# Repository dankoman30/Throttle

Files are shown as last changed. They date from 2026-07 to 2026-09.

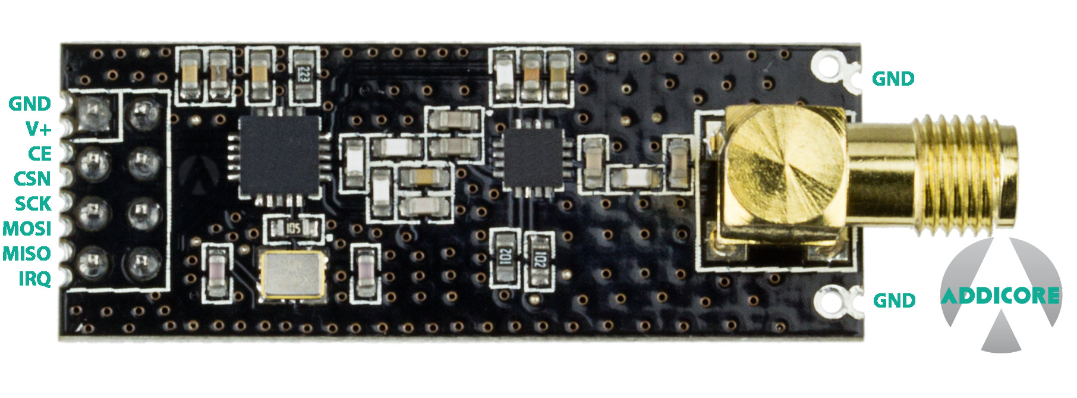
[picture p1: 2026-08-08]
DEVELOPMENT/assets/nRF24L01+/pinout.png

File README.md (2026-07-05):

# Throttle — drive-by-wire paramotor throttle

**A wireless, fail-safe paramotor throttle — squeeze the trigger, a radio link drives a servo that works the engine's throttle. No long mechanical cable running from your hand to the motor.**

The servo is **remote-mounted** (on the frame, not bolted to the engine) and pulls the throttle via a short push-pull cable — for space, vibration isolation, and a spring-return-to-idle fail-safe. See [`docs/PROJECT_DESIGN.md`](docs/PROJECT_DESIGN.md).

`Status: in development · pre-hardware · not flight-ready` — see [Status](#status--not-flight-ready).

Open firmware (and, in time, hardware) for a **drive-by-wire paramotor throttle**.
A handle-mounted STM32 reads a trigger, kill switch, start button, cruise button
and accessory switches, and transmits 5-byte packets at 80 Hz over an nRF24L01+
radio to a second STM32 near the engine. The receiver validates every packet,
runs a kill/start/run state machine, and drives a servo that pulls the physical
throttle cable — with an independent loss-of-signal watchdog that ramps the
engine back to idle if the link drops.

## Features

- **Fail-safe wireless kill** — latched on the handle so a brief press survives dropped packets; wired normally-closed so a broken wire = kill, with debounce against vibration glitches.
- **Loss-of-signal watchdog** — independent of the packet path; ramps the throttle to idle then holds it if the radio link drops, and won't hand control back until the link is stably restored.
- **Hold-to-crank electric start** — the starter runs while you hold the button and releases when the engine catches; bounded by a fast loss-of-signal abort and a hard max-crank cap so it can never run away.
- **Cruise control** — hold throttle hands-free; disengages on a second press, kill, or an upward trigger override. Resolved on the handle so the watchdog still overrides it.
- **Accessory outputs** — switch lights, smoke, etc., kept deliberately outside the safety-critical state machine.
- **Local battery monitors** — a 3–4 LED bar + low-battery buzzer on *each* unit, no return telemetry.
- **Layered safety by design** — packet validation (sync → CRC8 → sequence), kill-always-first command ordering, rate-limited servo motion, and a mechanical kill wired straight to the ignition, independent of any firmware.

> [!WARNING]
> ## Safety disclaimer — read this
>
> This is **DIY, safety-critical hardware**. It controls the throttle and
> ignition of a running two-stroke engine strapped to a person in flight.
>
> - It is **not certified** to any aviation or functional-safety standard, and
>   makes no claim of airworthiness.
> - You build, wire, configure, and fly it **entirely at your own risk**.
> - The firmware is provided **"AS IS", with no warranty** of any kind (see
>   `LICENSE`).
> - The design depends on a **mechanical kill switch wired directly into the
>   ignition line, independent of this firmware**. Do not remove it. The
>   authors accept no responsibility for injury or damage arising from use of
>   this project, from forks or modifications, or from removal or defeat of any
>   safety feature (mechanical kill, loss-of-signal watchdog, fail-safe wiring).
>
> If you intend to build and fly this, having someone familiar with the legal
> and liability implications of open safety-critical hardware review your plans
> is strongly advised.

## Status — not flight-ready

This project is **incomplete** and under active development. Known gaps that are
safety-relevant:

- **Engine-caught detection (`STARTING` → `RUNNING`) is not implemented.** The
  signal that tells the receiver the engine actually started (RPM sense,
  vibration, or a timed window) has not been chosen or built. **Do not fly**
  assuming the start sequence is finished.
- The firmware `.c` files are **HAL/RF24 stubs** — peripheral inits, the radio
  port, ADC/GPIO/PWM, and battery voltage divider values are placeholders that
  must be filled in during board bring-up.
- Timing/threshold constants are bench-tuning starting points, not validated.

See `docs/OPEN-ITEMS.md` for the full living list of unresolved questions and
action items, and `docs/PROJECT_DESIGN.md` for the rationale behind the design.

## Layout

```
src/common/     shared contract: packet protocol, CRC8, battery monitor (must stay identical both ends)
src/handle/     transmitter firmware (trigger, kill, start, cruise, accessories, battery)
src/receiver/   receiver firmware (validation, state machine, servo, watchdog, battery)
test/           host-side pure-logic tests (no hardware needed)
hardware/       schematics, PCB, mechanical, BOM (to come)
docs/           design doc, open items, architecture decision records
```

## Build & test

There is **no committed embedded build system yet** — building the firmware for
real requires generating an STM32CubeIDE project, wiring the peripheral inits,
and linking a HAL port of RF24 (TMRh20).

The pure logic (CRC8, sequence rollover, battery mapping, cruise, kill debounce)
can be tested on your PC with any C compiler:

```sh
# host-side logic tests
gcc -Wall -Wextra -Isrc/common -Itest test/test_logic.c -o test_logic && ./test_logic

# compile-check the firmware (stubs; no main/hardware)
gcc -c -Wall -Wextra -Isrc/common src/handle/handle_firmware.c    -o handle.o
gcc -c -Wall -Wextra -Isrc/common src/receiver/receiver_firmware.c -o receiver.o
```

## License

- **Firmware / software:** GNU General Public License v3.0-or-later — see
  `LICENSE`. Derivatives that are distributed must remain open under the same
  terms.
- **Hardware** (schematics, PCB, mechanical designs, once added): will be
  licensed under **CERN-OHL-S** (strongly reciprocal). See `hardware/README.md`.

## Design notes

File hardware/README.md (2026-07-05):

# Hardware

Schematics, PCB layouts, mechanical designs, and BOM for the throttle system.

Nothing here yet — this tree is scaffolding for upcoming design work:

```
schematics/   handle + receiver schematics (kill line, relays, RF, battery/LED bar, buzzer)
pcb/          board layouts
mechanical/   servo bracket, enclosures, mounting, connector plan
bom/          bill of materials
```

## License

Hardware design files in this directory (once added) are intended to be licensed
under **CERN-OHL-S v2** (CERN Open Hardware Licence, Strongly Reciprocal), which
is written for physical/board designs — separate from the **GPL-3.0-or-later**
that covers the firmware under `src/`. The `hardware/LICENSE` file will be added
alongside the first real design files.

## Safety note

See the top-level `README.md` safety disclaimer. In particular, the **mechanical
kill switch must be wired directly into the ignition kill line, independent of
any microcontroller or radio**, and must function with zero power to the
electronics. It is not — and must not be — controlled by firmware.

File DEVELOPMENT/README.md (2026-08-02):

# DEVELOPMENT

Bench-test rigs for bring-up and validation on real hardware, separate from
`src/` (the production firmware), `hardware/` (final board designs), and
`docs/` (project-level docs/ADRs).

Each subfolder here targets one physical unit and is meant to be built and
flashed with STM32CubeIDE against a dev board on a breadboard — proving out
logic before the corresponding real hardware (radio link, relays, production
servo, etc.) is wired up.

```
receiver/      bench rig for the receiver/servo-driver unit (current focus)
transmitter/   bench rig for the handle/trigger unit (deferred until receiver proves out)
```

**Safety note:** nothing under `DEVELOPMENT/` drives a real engine. The
receiver bench rig's kill/starter outputs are LED indicators only — no
relay, no ignition line, no starter solenoid. The mechanical kill switch
requirement in the top-level `README.md` and `hardware/README.md` still
applies to any real installation; it is not superseded by anything here.

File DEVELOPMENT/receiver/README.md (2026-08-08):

# DEVELOPMENT/receiver — bench rig (no radio yet)

**This doc covers the bench rig (`firmware/`) specifically.** For the
production receiver (real radio/servo/relays, not breadboard simulation),
see `receiver-prod/README.md`.

Runs the **real** receiver safety state machine
(`src/receiver/receiver_firmware.c`, completely unmodified) on an
STM32L432KC (Nucleo-32), fed by breadboard buttons and a potentiometer
instead of the nRF24L01+ radio link. This proves out kill/start/throttle/
watchdog behavior on real hardware before the radio, relays, and production
servo are wired up.

## What this does and doesn't test

**Does:**
- The receiver's packet validation (sync/CRC8/sequence), the kill latch and
  its stickiness, gated start (manual crank model), rate-limited throttle,
  and the independent loss-of-signal watchdog — all running the actual
  functions from `src/receiver/receiver_firmware.c` via
  `#include "receiver_firmware.c"` in `firmware/Src/bench_app.c` (see
  `docs/bench-behavior.md` for why this reuse approach was chosen and
  exactly what runs).
- A hand-built cruise mirror (small, bench-only reimplementation of the
  handle's `apply_cruise()`), since cruise is normally resolved on the
  handle and the receiver treats it as transparent.

**Does not test:**
- The radio link itself (packet loss patterns, RF interference, range).
- The starter solenoid / ignition-cut relays (LED stand-ins only here).
- Real engine-caught detection — the project has no tach (see
  `docs/OPEN-ITEMS.md`, ADR 0007); the green "engine running" LED here is a
  manual-release proxy, not a sensor reading.

## Layout

```
docs/
  wiring.md           pin-by-pin connections and resistor values
  cubemx-config.md    step-by-step CubeMX peripheral/pin/clock setup
  bench-behavior.md   full behavior spec + verification checklist
schematics/
  receiver-bench.md   breadboard schematic (markdown/ASCII)
firmware/
  Src/bench_app.c        ingestion (buttons/pot) + actuation (servo/display/buzzer/LEDs)
  Inc/bench_app.h
```

`firmware/` is a full STM32CubeMX-generated project (HAL/CMSIS drivers under
`Drivers/`, `firmware.ioc`, `.project`/`.cproject`) targeting the
NUCLEO-L432KC, with `bench_app.c`/`bench_app.h` wired into `main.c`. See
`docs/cubemx-config.md` for how it was configured and how to regenerate it.

## Board mod required

This board revision ships with solder bridges `SB16`/`SB18` closed by
default, which internally tie `PA6`↔`PB6` and `PA5`↔`PB7` together —
directly conflicting with this pin plan (kill button + yellow LED, servo
PWM + heartbeat LED). **Cut both before wiring anything** — see "Required
board mod" in `docs/wiring.md`.

## Bill of materials (this bench rig)

- STM32L432KC Nucleo-32
- 3× momentary pushbutton (start, cruise, kill)
- 1× B103 (10kΩ linear) potentiometer
- 1× piezo buzzer
- 1× 5611AH single-digit 7-segment LED display
- 1× SG90 micro servo
- 4× LED (green, red, yellow, + 1 for heartbeat — any color)
- Resistors: 7× for the 7-segment + 4× for the LEDs (~220–330Ω, see `docs/wiring.md`)

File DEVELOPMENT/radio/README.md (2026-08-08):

# DEVELOPMENT/radio — RF24 HAL port & radio link bring-up

**Status: all hardware has arrived (2026-08-06). Nothing built yet — starting
bring-up now.** This doc exists so picking this up doesn't require
re-deriving context from scratch.

## What this covers

Bringing up the actual nRF24L01+ link between `handle` and `receiver`. Both
`src/handle/handle_firmware.c` and `src/receiver/receiver_firmware.c` currently
have the entire radio path commented out (`radio.begin()`, `radio.write()`,
`radio.available()`/`radio.read()`, etc.) — the packet/state-machine logic on
both ends is already proven (`DEVELOPMENT/receiver/`), but nothing has actually
gone over the air yet. `docs/OPEN-ITEMS.md` flags the RF24 HAL port as staying
"on the critical path" for exactly this reason.

## Hardware inventory

**All arrived:**
1. **4x nRF24L01+PA+LNA modules**, from [Addicore](https://www.addicore.com/products/nrf24l01-pa-lna-with-antenna-2-4ghz-wireless-transceiver)
   (2 for the link + 2 spares). Clone chips (silkscreened as genuine Nordic
   but actually `SI24R1`/Beken parts) are a known problem for this exact
   module category and can't be reliably told apart by inspection (Nordic is
   fabless; markings vary by fab run) — buying multiple units from one
   reputable, consistent source is the practical mitigation, per ADR 0005's
   "not clone boards" requirement.
2. **2 additional STM32L432KC Nucleo-32 boards**, ordered directly from ST.
   Combined with the two already on hand, that's **4 total boards — only 1
   (the current receiver bench rig) has SB16/SB18 removed.** The other
   existing board and both new ones are stock/unmodified. See the SPI pin
   mapping note below before wiring any of the three unmodified boards for
   radio — it's directly relevant.
3. **Decoupling capacitors**, from Amazon:
   - ALLECIN 24-value electrolytic capacitor assortment kit (0.1µF–1000µF,
     10V/16V/25V/50V). Use the **16V or 25V** parts for this (not the 10V
     ones) — margin above the 3.3V rail, per the reasoning below.
   - 24-value / 480pc multilayer ceramic capacitor assortment kit
     (10pF–10µF) — covers the needed 0.1µF (100nF) many times over.
   - At each module's V+/GND pins, as close to the module as physically
     possible: one bulk **10–100µF** (from the electrolytic kit, 16V/25V) +
     one **0.1µF ceramic** (from the ceramic kit). **Known failure mode
     without this**: the PA+LNA variant draws real current spikes on TX
     (order ~100+mA) that a Nucleo's small onboard 3.3V LDO isn't sized for —
     one of the most common causes of "the radio just doesn't work / works
     intermittently" reports for this module. If it's still flaky with local
     decoupling, move to a dedicated 3.3V supply rather than the Nucleo's
     onboard rail.
4. **LONELY BINARY 8-Channel 24MHz USB Logic Analyzer Kit** (Amazon, ~$20;
   includes base module, breadboard breakout board, USB-A + Type-C cables,
   test clips, alligator clips). This is the same class of Cypress
   FX2LP-based hardware behind most "Saleae Logic clone" listings — pair it
   with **sigrok / PulseView** (free, open source) via its `fx2lafw` driver —
   worth doing a first smoke test now (confirm PulseView detects it) rather
   than waiting until it's needed mid-bring-up. PulseView has a **built-in
   SPI protocol decoder**, so feeding it
   SCK/MOSI/MISO/CSN shows decoded byte-level SPI transactions directly, not
   just raw waveforms — exactly what's needed to check nRF24 register
   reads/writes against the datasheet. Already on the toolchain wishlist in
   `docs/PROJECT_DESIGN.md`; would have shortened the SB16/SB18 debugging
   saga considerably had we had register-level SPI visibility instead of
   just GPIO reads. **Caution**: these clones typically have minimal input
   protection and are 3.3V-logic-only — fine for this SPI work (everything
   here is 3.3V) but don't probe 5V signals (e.g. the servo's 5V rail) with
   it.

No level shifting needed for the radio modules either way — their SPI inputs
are 5V-tolerant and the onboard regulator accepts 1.9–3.6V, a direct match
for the L432KC's 3.3V logic.

## SPI pin mapping: use PB3/PB4/PB5, not the PA5/PA6/PA7 default

**Important given 3 of the 4 boards don't have SB16/SB18 removed.** The
STM32L432KC's *default* SPI1 alternate-function mapping is `PA5`=SCK,
`PA6`=MISO, `PA7`=MOSI (AF5) — which is exactly the pin pair SB16/SB18
bridge to `PB6`/`PB7`. Using the default mapping on any unmodified board
would reproduce the same "two header pins are secretly one net" problem that
caused the kill-button saga, except manifesting as corrupted/garbled SPI
transactions rather than a flat stuck signal — likely *harder* to diagnose.

STM32L432KC also supports an **alternate SPI1 mapping on `PB3`/`PB4`/`PB5`**
(also AF5). **Use that mapping in CubeMX for the initial bring-up boards** —
it sidesteps the solder-bridge pins entirely, so none of the 3 unmodified
boards need SB16/SB18 removed just to get SPI working. One cosmetic note:
`PB3` is wired to the onboard LED `LD3`, so it'll flicker with SPI clock
activity — harmless, not a real conflict.

**Correction: this does not solve the receiver bench rig's pin problem** —
an earlier draft of this note incorrectly claimed it did. `PB4`/`PB5` are
already committed there too — Green LED and Red LED respectively
(`../receiver/docs/wiring.md`) — so the alternate mapping just trades one
conflict (solder bridges) for a different one (existing LED wiring) on that
specific board. That board's issue is genuinely zero free pins, not a
solder-bridge issue, and is already tracked separately below (Nucleo-64
fallback). The SPI mapping choice here only matters for the 3 fresh,
otherwise-unwired boards used for initial bring-up.

## Open design decision: adapt an existing STM32 fork, or write a minimal custom driver

Two community STM32 ports of TMRh20's RF24 library exist:
[TheDIYGuy999/RF24_STM32](https://github.com/TheDIYGuy999/RF24_STM32) and
[MarkKharkov/RF24](https://github.com/MarkKharkov/RF24). At least one report
([nRF24/RF24#501](https://github.com/nRF24/RF24/issues/501)) got basic SPI
communication working but had unreliable inter-node communication — so
adapting one of these isn't a guaranteed shortcut, just a possible head start.

Alternative: a minimal driver written directly against the nRF24L01+
datasheet's register map. Our protocol only needs a small slice of what the
full library supports — fixed 5-byte writes (handle), poll-based
`available()`/`read()` (receiver, no interrupt-driven mode needed), no ack,
no dynamic payload, no multicast. That's plausibly *less* total code than
untangling someone else's partial port, and easier to safety-review since
it would only contain what's actually used.

**Decided, 2026-08-06: minimal custom driver.** Implemented as
`DEVELOPMENT/radio/spi-bringup/spi-bringup/{Inc,Src}/nrf24.c/.h` — a
register-level driver against the nRF24L01+ (Plus) datasheet covering only
what this project's link needs (single/multi-byte register read/write,
init with no-ack/no-retry/250kbps+PA_HIGH/fixed 5-byte payload). Chosen over
adapting TheDIYGuy999/RF24_STM32 or MarkKharkov/RF24 per the reasoning
above and ADR 0006 (pure STM32 HAL, no Arduino/STM32duino).

## Known integration constraint for later: pin budget

The receiver bench rig already committed **all 17 free GPIOs** on the
L432KC's Arduino-style header — "no margin" per `../receiver/docs/wiring.md`.
SPI (SCK/MOSI/MISO/CSN) + CE needs 4 more pins than that board has free
(IRQ isn't needed since we poll, matching the commented-out
`radio.available()` calls already in both firmwares). This doesn't block
the initial bring-up here (happening on a fresh, otherwise-unused board),
but merging radio into the actual populated receiver rig later will need
either freeing pins (e.g. dropping the 7-segment readout or heartbeat LED)
or bumping to a Nucleo-64 — already noted as the fallback in
`docs/OPEN-ITEMS.md`.

## Suggested bring-up order (once hardware arrives)

1. **Single board + single module**: confirm SPI transactions work at all —
   read back a known register (e.g. `CONFIG`, datasheet default `0x08`) and
   confirm it matches. Logic analyzer on SCK/MOSI/MISO/CSN/CE to sanity-check
   the transaction shape against the datasheet timing diagrams.

   **Done, 2026-08-06.** `DEVELOPMENT/radio/spi-bringup/` (stock/unmodified
   Nucleo, SPI1 on PB3/PB4/PB5) read back `CONFIG` (addr `0x00`) as `0x08`
   and `STATUS` as `0x0E` — both exactly the nRF24L01+ datasheet's
   power-on-reset defaults for a fresh module. Confirmed via CubeIDE
   debugger (breakpoint after the transaction, `rx_buf[0]`/`rx_buf[1]`
   inspected as Expressions), not yet cross-checked against the logic
   analyzer's captured waveform — worth doing at some point for the
   SPI-mode/timing sanity check, but not blocking since the chip is already
   responding with correct data.

   **Multi-byte register read/write also confirmed, 2026-08-06.** The
   `nrf24.c` driver's `nrf24_write_reg_n`/`nrf24_read_reg_n` (used for the
   5-byte `RX_ADDR_P0`/`TX_ADDR` address registers) round-tripped correctly
   on hardware: after `nrf24_init()`, `CONFIG` read back `0x0A`, `RF_SETUP`
   read back `0x24`, and `RX_ADDR_P0` read back `{0xE7,0xE7,0xE7,0xE7,0xE7}`
   — all matching the values the driver itself wrote, confirming both the
   single- and multi-byte read and write paths. (An early single-call-per-byte
   implementation of the `_n` functions read back all-zero instead; fixed by
   building one cmd+data buffer and sending it in one `HAL_SPI_TransmitReceive`
   call, matching the single-register functions' already-proven pattern.)

2. ~~Decide fork-vs-custom-driver~~ — done, see above.
3. **Two boards + two modules**: a raw TX/RX smoke test independent of
   `handle_firmware.c`/`receiver_firmware.c` — e.g. one side sends an
   incrementing counter, the other prints/blinks it. Proves the link itself
   before touching either firmware.

   **Done, 2026-08-06.** Board A (PTX role) sends an incrementing counter
   every ~300ms; board B (PRX role) receives it and stores the value for
   debugger inspection (`rx_last_counter`), confirmed climbing by 1 each
   time, matching board A. Two real bugs found and fixed along the way —
   see `docs/decisions/0005-radio-choice-and-ignition-emi.md`'s 2026-08-06
   addendum for the full detail, since both are likely clone-chip symptoms
   relevant to eventual production hardware sourcing:
   - `nrf24_send_payload()` now clears `STATUS` and flushes the TX FIFO
     after every send (not just once at init) — without this, the TX
     board's FIFO latched permanently full (`MAX_RT` stuck set) within a
     few send cycles, despite `EN_AA`/`SETUP_RETR` both confirmed `0x00`.
   - `RF_SETUP` is temporarily `1Mbps` instead of the originally-intended
     `250kbps` — at 250kbps, zero packets were ever received even with the
     above fix and both boards side by side with antennas seated; switching
     to 1Mbps with no other change made reception immediately reliable.
     **This is a bring-up diagnostic swap, not a data-rate decision** — see
     the ADR 0005 addendum before assuming it holds for other hardware.

4. **Only after that**: wire the real `radio.*` calls into
   `handle_firmware.c` and `receiver_firmware.c` (currently fully
   commented-out stubs) and re-verify both bench rigs end-to-end over real
   radio instead of GPIO-simulated input.

   **Driver promoted, 2026-08-07; firmware wiring still blocked.** The
   proven `nrf24.c`/`nrf24.h` driver now lives in `src/common/` (shared,
   real, compiled code - not the bring-up project's copy), parameterized
   via an `nrf24_handle_t` so handle and receiver each supply their own SPI
   peripheral and CE/CSN pins rather than relying on hardcoded globals. Both
   firmware files' stub comments were updated to reference the real
   `nrf24_*` API (replacing stale TMRh20/RF24-library-style pseudocode from
   before the fork-vs-custom-driver decision), but the calls themselves stay
   commented, not live, because two concrete prerequisites are still open:
   - **Receiver**: no free GPIOs for SPI+CE — the bench rig already
     committed all 17 (see "Known integration constraint" above). Needs
     either freeing pins or a Nucleo-64 before real pins can be assigned.
   - **Handle**: no real hardware project exists yet at all (unlike the
     receiver's `DEVELOPMENT/receiver/firmware/`) — only the bring-up boards
     have been wired/programmed so far.

   Host compile-checks (`test/test_logic.c` and both firmware
   `.c` files) still pass unchanged - `nrf24.h`/`nrf24.c` depend on the real
   STM32 HAL and are new, not part of either check.

## Related docs

- `docs/decisions/0005-radio-choice-and-ignition-emi.md` — why
  nRF24L01+PA+LNA specifically, and the EMI environment to design around
  once this is mounted near a running engine.
- `docs/decisions/0001-no-radio-ack.md` (see the 2026-08-02 addendum) — no
  radio-level ack on the control uplink; a telemetry downlink is deferred
  and out of scope here.
- `docs/OPEN-ITEMS.md` — "RF24 HAL port" (Firmware TODOs) and "RF range
  test" (Hardware TODOs) entries.
- `docs/PROJECT_DESIGN.md` — toolchain list (logic analyzer already listed
  there).

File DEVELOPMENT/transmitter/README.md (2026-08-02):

# DEVELOPMENT/transmitter

Placeholder. Bench-test rig for the handle/trigger unit — deferred until the
receiver bench rig (`../receiver/`) proves out the approach (reusing the real
`src/handle/handle_firmware.c` state logic via the same
`#include "handle_firmware.c"` technique, driven by local trigger
pot/kill-switch/start-button/cruise-button input instead of real HAL reads).

Nothing here yet.

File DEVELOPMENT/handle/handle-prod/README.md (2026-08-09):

# DEVELOPMENT/handle/handle-prod — production handle/transmitter

Runs the **real** handle kill-latch/cruise/start-hold logic
(`src/handle/handle_firmware.c`, unmodified except small, reviewed hardware
fill-ins guarded by `HANDLE_PROD_BOARD` — see `Src/handle_app.c`'s header
comment) on an STM32L432KC (Nucleo-32), driving **real hardware**: the
trigger position sensor, kill/start/cruise/AUX1/AUX2 inputs, the nRF24L01+
radio TX, a tri-color status LED, and two AUX indicator LEDs. Compare
`DEVELOPMENT/receiver/receiver-prod/`, the same `#include`-reuse pattern
applied to the receiver side.

## Layout

```
docs/
  wiring.md         pin-by-pin connections, resistor values, known wiring gaps
Inc/handle_app.h     status LED color/priority behavior
Src/handle_app.c      real GPIO/ADC ingestion + radio TX + LED actuation
handle-prod.ioc       STM32CubeMX project file
```

Full STM32CubeMX-generated project (HAL/CMSIS drivers under `Drivers/`,
`STM32CubeIDE/.project`/`.cproject`) targeting NUCLEO-L432KC, with
`handle_app.c`/`handle_app.h` wired into `main.c`. Same linked-resource
caveat as receiver-prod: this project's `.project` tracks source files as
an explicit list, not a live directory scan — a new file in `Src/`/`Inc/`
needs a manually-added `<link>` entry or the IDE won't see it.

## Board

Reuses "board A" from `DEVELOPMENT/radio/spi-bringup/` — its radio wiring
(`NRF_CE`=`PA1`, `NRF_CSN`=`PA3`, SPI1 on `PB3`/`PB4`/`PB5`) already
matched this project's pin plan exactly, so it carried over unchanged;
everything else (trigger, kill/start/cruise/AUX1/AUX2, status + indicator
LEDs) was wired fresh on top. Same SB16/SB18-avoidance reasoning as
receiver-prod - see `docs/wiring.md` for the full pin table and why it
works.

## Status

- **2026-08-09: AUX2 restored, AUX1/AUX2 given distinct behavior,
  confirmed on real hardware.** AUX2 (smoke) was reinstated once adding
  its switch plus two indicator LEDs still fit the pin budget (16 of 17).
  AUX1 (strobe) is now LATCHED in firmware - toggle on/off on successive
  presses, same shape as `apply_cruise()`'s toggle - while AUX2 stays
  purely momentary, matching how AUX1 used to work. Deliberately kept
  both fully out of the receiver's kill/start/throttle state machine
  (discussed and reconfirmed, not just left over from before AUX2 was
  removed) - see `docs/OPEN-ITEMS.md`. Both indicator LEDs and both
  receiver-side outputs confirmed tracking correctly over the radio link.
- **2026-08-08: full command path confirmed on real hardware** — radio
  uplink to a receiver board, trigger position driving the servo live over
  the air, the start button correctly showing the cranking indication,
  cruise engage/disengage, and AUX1, all working end-to-end. Two real bugs
  were caught and fixed live during bring-up, both worth remembering:
  - **Cruise and AUX1 wired to GND instead of 3V3.** Those two inputs use
    the opposite pull convention from kill/start (pull-down vs pull-up),
    so their "other leg" needs to go to 3V3 - wiring all four buttons to
    GND by habit meant cruise/AUX1 could never read HIGH, so neither
    button did anything until corrected. See `docs/wiring.md`'s pin table
    note.
  - **Trigger ADC pull-down initially wired in series instead of
    parallel** - spliced into the wiper wire itself rather than as a
    separate leg to GND, which wouldn't have provided the intended
    fail-safe protection (the pin would still float if that wire broke)
    and would have starved the ADC's short sampling time. Corrected before
    it caused a real symptom.
- **Known, deliberate gap: the kill switch is currently a normally-open
  bench stand-in**, bridged closed with a jumper wire to unblock testing
  everything else. This design requires a genuinely normally-closed
  switch/contact block - swapping it is tracked in `docs/OPEN-ITEMS.md`.
- **Not yet measured**: real trigger ADC min/max at full release/pull (see
  `docs/wiring.md` "Trigger"); handle battery power source (sensing was
  dropped entirely, but the board still needs a real pack for field use).

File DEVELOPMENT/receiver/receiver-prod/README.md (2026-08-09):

# DEVELOPMENT/receiver/receiver-prod — production receiver

Runs the **real** receiver safety state machine
(`src/receiver/receiver_firmware.c`, unmodified except three small, reviewed
hardware fill-ins guarded by `RECEIVER_PROD_BOARD` — see `Src/prod_app.c`'s
header comment) on an STM32L432KC (Nucleo-32), driving **real hardware**:
the nRF24L01+ radio link, a servo, a tri-color status LED, and a local
start button — not breadboard simulation. Compare
`DEVELOPMENT/receiver/firmware/` (the bench rig), which proves out the same
state machine fed by local buttons/a pot instead of the radio, and doesn't
drive real actuator hardware.

## Layout

```
docs/
  wiring.md        pin-by-pin connections, resistor values, known wiring gaps
Inc/prod_app.h      LED behavior spec (heartbeat/kill/cranking/battery-low)
Src/prod_app.c      radio ingestion + servo/LED/relay/accessory actuation
receiver-prod.ioc    STM32CubeMX project file
```

Full STM32CubeMX-generated project (HAL/CMSIS drivers under `Drivers/`,
`STM32CubeIDE/.project`/`.cproject`) targeting NUCLEO-L432KC, with
`prod_app.c`/`prod_app.h` wired into `main.c`. Note: this project's
`.project` tracks source files as an explicit linked-resource list (not a
live directory scan) — see the commit that added `prod_app.c` if a new file
in `Src/`/`Inc/` doesn't show up in the IDE after a refresh.

## Board

Reuses "board B" from `DEVELOPMENT/radio/spi-bringup/` — the pin plan
deliberately avoids the `PA5`↔`PB7`/`PA6`↔`PB6` solder-bridge pairs, so this
board's SB16/SB18 were **not** desoldered (unlike the bench rig's board,
which required that mod). See `docs/wiring.md` for the full pin table and
why this works.

## Status

- **2026-08-09: AUX2 restored and confirmed on real hardware.** AUX2/PA10
  was never actually un-assigned in CubeMX during its 2026-08-08 removal,
  so restoring it was a code-only change (`apply_aux_outputs()` +
  `prod_app.c`'s GPIO write). Confirmed tracking the handle's AUX2 level
  correctly over the radio link, alongside AUX1 (now latched on the
  handle side, though this receiver treats both identically as plain
  level flags either way).
- **2026-08-08: Stage 1 confirmed on real hardware** (standalone, no radio
  link needed) — heartbeat LED blinking, servo settling at idle, and the
  local start button working end-to-end: press → blue LED (cranking),
  release → green LED (engine-running proxy). This is the first real-
  hardware confirmation of the local start button feature added this
  session (see the safety-reviewer-verified fix in
  `src/receiver/receiver_firmware.c`'s git history for the trigger-source
  tracking that closes the loss-of-signal-abort gap).
- **2026-08-08: Stage 2 confirmed on real hardware — full radio→servo path.**
  `spi-bringup`'s TX role now sends a real, protocol-valid
  `throttle_packet_t` (correct sync byte, sequence number, CRC8) with the
  throttle field slowly triangle-sweeping between idle and a moderate
  value. Board B's servo visibly tracked the sweep, live over the air —
  direct confirmation that `on_packet_received()`'s sync→CRC8→sequence
  validation is passing on real hardware for the first time, and that
  received throttle correctly flows through the rate-limited
  `step_toward_target()` path to the servo PWM. This is the first
  confirmed real-hardware run of the complete radio→validate→throttle→
  servo chain.
- **2026-08-08: Stage 3 confirmed on real hardware — wireless KILL and
  START, both correctly gated.** `spi-bringup`'s TX role now also
  auto-tests `CMD_FLAG_START_REQ` (every ~6s, held ~0.9s at idle throttle,
  well under `MAX_CRANK_MS` - always ends via voluntary release) and
  supports a debugger-triggered one-shot `CMD_FLAG_KILL` (not automatic,
  since KILL is sticky on the receiver and firing it on a timer would lock
  board B mid-test). Confirmed: wireless START correctly cycles blue
  (cranking) → green (engine-running proxy, stays lit - visible as an
  amber/yellow tint against the still-blinking red heartbeat) → back to
  normal; wireless KILL correctly latches solid red and stays there
  through a real board-A debug-session interruption, requiring a genuine
  board B power-cycle to re-arm (confirmed the local start button remains
  independently functional after re-arm, and that the TX side's one-shot
  `tx_send_kill` flag correctly self-resets). This is full real-hardware
  confirmation of every command path this board handles - kill, start
  (both wireless and local), and throttle - all currently deferred parts
  (kill relay, starter relay, battery sense) are wiring gaps, not logic
  gaps.
- **Known, deliberate wiring gaps**: kill relay, starter relay, battery
  sense — see `docs/wiring.md` "Known gaps".

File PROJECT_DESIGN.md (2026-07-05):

# Paramotor Drive-by-Wire Throttle — Project Design Doc

## Overview
Drive-by-wire paramotor throttle. Handle-mounted STM32 reads trigger position + kill switch + start button, transmits over 2.4GHz (nRF24L01+) to a remote-mounted STM32 near the engine, which drives a servo that pulls the physical throttle cable.

## Architecture

**Handle unit**
- STM32 (Nucleo-32 STM32L432KC or STM32G031 for prototyping)
- Reads trigger position via ADC (12-bit), smoothed with a simple exponential moving average filter
- Reads wireless kill switch and start button (start requires hold, not a single tap)
- Transmits fixed-size packet at 80Hz over nRF24L01+PA+LNA

**Remote unit**
- STM32 (same board family as handle for prototyping)
- Receives packets, validates, runs state machine
- Drives servo (rate-limited) which pulls throttle cable
- Independent watchdog timer for loss-of-signal handling

**Mechanical backup kill switch**
- Completely independent of MCU/radio — wired directly into the ignition kill line (grounds CDI/kill wire on most 2-stroke setups)
- Must function with zero power to any electronics
- Physically distinct in feel/location from trigger and start button, mounted for by-touch operation
- Use locking connectors (JST-SM minimum, Deutsch/Amphenol preferred) given vibration exposure

## Packet Structure (handle → remote, 5 bytes)
| Field | Size | Notes |
|---|---|---|
| Sync byte | 1 | Fixed value 0xA5, marks valid packet start |
| Sequence number | 1 | Rolls 0–255, detects stale/dropped/duplicate packets |
| Throttle position | 1 | 0–255 mapped from handle ADC |
| Command flags | 1 | Bitfield: bit0=kill, bit1=start-request |
| CRC8 | 1 | CRC-8/MAXIM over first 4 bytes, independent of radio-layer CRC |

Command flags are bits, not an enum values, so kill and start states are never ambiguous and kill can always be checked first regardless of what else is in the packet.

## Receiver State Machine
States: `IDLE_SAFE`, `RUNNING`, `STARTING`, `KILLED`

Per-packet validation order (discard entirely if any step fails):
1. Sync byte check
2. CRC8 check
3. Sequence number check (must be newer, accounting for 0–255 rollover)

Per-packet command handling order (kill always checked first):
1. **Kill** — if set, cut ignition immediately, → `KILLED`, ignore rest of packet
2. **Killed state is sticky** — only a physical/mechanical re-arm can clear it, no wireless command can
3. **Start** — only actionable from `IDLE_SAFE`, only if packet throttle ≤ idle threshold, only if link isn't in post-loss recovery window
4. **Throttle** — applied only if not in post-loss recovery window, rate-limited per tick

## Watchdog / Loss-of-Signal Logic
Runs independently of packet reception, on its own timer:
- **Threshold A** (~175ms since last valid packet): begin linear ramp of throttle down to idle over a fixed duration (~400ms) — not instant, to avoid a sudden idle mid-flight being its own hazard
- **Threshold B** (~600ms): fully committed to idle, hold, mark link as "recovering"
- **Link recovery**: once packets resume, link must be continuously valid for a stability window (~300ms) before throttle is allowed to respond to pilot input again — prevents a flickering link from causing throttle hunting

All thresholds and ramp durations are **fixed compile-time constants**, tuned during bench testing, not adjustable in flight.

## Design Decisions Log
- **No radio-level ack** (`setAutoAck(false)`) — fixed-rate send + sequence number + watchdog covers command delivery without ack round-trip latency. Open question: revisit for kill specifically if confirmed-delivery matters more there.
- **CRC8/MAXIM chosen** over rolling custom checksum — small, well-tested, easy to hand-verify against known test vectors.
- **Servo spec** — pull force/travel must be measured directly off the actual throttle cable (fish scale across full stroke, not just one point) before ordering. Ballpark 15–25kg·cm digital metal-gear servo, continuous-duty rated.
- **nRF24L01+PA+LNA** (not bare module) — range margin needed given outdoor use, body/frame in the RF path. Buy from reputable supplier (Mouser/DigiKey), not cheap clones, given safety-critical context.

## Open Items / Not Yet Decided
- What signal indicates "engine caught" to transition `STARTING` → `RUNNING`? (RPM sense, vibration switch, or timed window — needs to be picked before that transition can be implemented)
- Actual measured distance/RF environment between handle and remote unit (through frame/cage/body) — determines whether PA+LNA gives enough margin
- Final servo selection pending cable force measurement
- Whether kill command should get an ack/confirmed-delivery path

## Toolchain
- STM32CubeIDE (includes CubeMX for peripheral config)
- ST-Link drivers (built into Nucleo boards)
- RF24 by TMRh20 (needs STM32 HAL port — original is Arduino-first)
- Git for version control
- Serial terminal (PuTTY or CubeIDE console) for debug prints
- Logic analyzer (cheap Saleae-compatible) for packet timing / PWM / kill relay verification
- Oscilloscope for servo PWM and kill line signal integrity checks

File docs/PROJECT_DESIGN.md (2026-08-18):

# Paramotor Drive-by-Wire Throttle — Project Design Doc

## Overview
Drive-by-wire paramotor throttle. Handle-mounted STM32 reads trigger position + kill switch + start button, transmits over 2.4GHz (nRF24L01+) to a remote-mounted STM32 near the engine, which drives a servo that pulls the physical throttle cable.

## Architecture

**Handle unit**
- STM32 (Nucleo-32 STM32L432KC or STM32G031 for prototyping)
- Reads trigger position via ADC (12-bit), smoothed with a simple exponential moving average filter
- Reads wireless kill switch and start button (start requires hold, not a single tap)
- Transmits fixed-size packet at 80Hz over nRF24L01+PA+LNA

**Remote unit**
- STM32 (same board family as handle for prototyping)
- Receives packets, validates, runs state machine
- Drives a **remote-mounted servo** (rate-limited) that actuates the engine's throttle **through a cable** (see below)
- Independent watchdog timer for loss-of-signal handling

**Throttle actuation — remote-mounted servo + cable (important)**
- The servo is **NOT mounted at the engine's throttle/carburetor**. It is mounted somewhere convenient on the frame/cage and connected to the engine throttle arm by a **push-pull / Bowden cable**. This is a deliberate design choice:
  - **Space:** the area right at the carb throttle is cramped; remote mounting gives placement freedom.
  - **Vibration:** keeping the servo off the engine spares it the worst of the 2-stroke vibration (fewer failures, better servo life).
  - **Serviceability / RF:** the receiver + servo can sit where wiring, antenna placement, and cooling are easier.
- **Fail-safe direction:** the carburetor's own **return spring pulls the throttle to idle**; the servo pulls *against* it to open. So a depowered servo, a servo failure, or a detached/broken actuation cable lets the spring return the engine to **idle** — the mechanical counterpart of the loss-of-signal watchdog. Confirm the throttle has a positive return-to-idle spring and that the linkage can never jam open.
- **Consequences to design for:** the Bowden cable adds **friction/stiction** (measure pull force through the *full installed cable run*, not the bare throttle cable), routing must avoid tight bends, and the run must tolerate **engine movement** on its rubber mounts (the engine shifts relative to the frame). Full servo travel must still map to the full throttle stroke after any cable slack/stretch.

**Mechanical backup kill switch**
- Completely independent of MCU/radio — wired directly into the ignition kill line (grounds CDI/kill wire on most 2-stroke setups)
- Must function with zero power to any electronics
- Physically distinct in feel/location from trigger and start button, mounted for by-touch operation
- Use locking connectors (JST-SM minimum, Deutsch/Amphenol preferred) given vibration exposure

## Packet Structure (handle → remote, 5 bytes)
| Field | Size | Notes |
|---|---|---|
| Sync byte | 1 | Fixed value 0xA5, marks valid packet start |
| Sequence number | 1 | Rolls 0–255, detects stale/dropped/duplicate packets |
| Throttle position | 1 | 0–255 mapped from handle ADC |
| Command flags | 1 | Bitfield: bit0=kill, bit1=start-request |
| CRC8 | 1 | CRC-8/MAXIM over first 4 bytes, independent of radio-layer CRC |

Command flags are bits, not an enum values, so kill and start states are never ambiguous and kill can always be checked first regardless of what else is in the packet.

## Receiver State Machine
States: `IDLE_SAFE`, `STARTING`, `KILLED` (no `RUNNING` — manual crank, no
tach, see ADR 0007; `IDLE_SAFE` covers both "engine off" and "engine
running", the pilot is the one who knows which)

Per-packet validation order (discard entirely if any step fails):
1. Sync byte check
2. CRC8 check
3. Sequence number check (must be newer, accounting for 0–255 rollover)

Per-packet command handling order (kill always checked first):
1. **Kill** — if set, cut ignition immediately, → `KILLED`, ignore rest of packet, also clears the latest recorded wireless start-request
2. **Killed state is sticky** — only a physical/mechanical re-arm can clear it, no wireless command can
3. **Start** — the packet handler only records the latest wireless start-request flag here; the actual gating and state transition happen independently of packet arrival (below), in `start_tick`, so a local start button at the receiver (ground-crew override, added 2026-08-07) also works with zero wireless packets ever received
4. **Throttle** — applied only if not in post-loss recovery window, rate-limited per tick

**Start gating (`start_tick`, independent of packet arrival, like the watchdog below):**
combines the latest wireless flag with a debounced local start button into one
signal, edge-triggers the crank start/stop off it — only actionable from
`IDLE_SAFE`, only at idle throttle, only outside the post-loss recovery
window, not during starter cooldown. Whichever crank begins records whether
wireless was involved in triggering it; the crank's own loss-of-signal abort
(part of the max-crank bounding logic) checks that recorded source rather
than the local button's live reading, so a stuck/faulty local button can't
silently defeat the fast abort for a wireless-triggered crank. There is
deliberately no local kill button — the unit's hardwired master kill switch
fills that role, same as the mechanical kill line described below.

## Watchdog / Loss-of-Signal Logic
Runs independently of packet reception, on its own timer:
- **Threshold A** (~175ms since last valid packet): begin linear ramp of throttle down to idle over a fixed duration (~400ms) — not instant, to avoid a sudden idle mid-flight being its own hazard
- **Threshold B** (~600ms): fully committed to idle, hold, mark link as "recovering"
- **Link recovery**: once packets resume, link must be continuously valid for a stability window (~300ms) before throttle is allowed to respond to pilot input again — prevents a flickering link from causing throttle hunting

All thresholds and ramp durations are **fixed compile-time constants**, tuned during bench testing, not adjustable in flight.

## Tunable Constants Reference

Every constant below is a compile-time `#define` — there is no runtime
tuning by design (see Design Decisions Log). All of them live in
`src/common/`, so they're shared by both `handle` and `receiver` builds:
change one, rebuild both firmwares, rerun `test/test_logic.c`, and
re-verify on the bench (or the `DEVELOPMENT/receiver` rig) before trusting
it in the air.

### Protocol timing & throttle shaping (`throttle_protocol.h`)

| Constant | Default | Controls | Tuning notes |
|---|---|---|---|
| `HANDLE_TX_RATE_HZ` | 80 | Packets/sec the handle transmits | `HANDLE_TX_PERIOD_MS` is derived from this — don't set it directly. Higher gives fresher throttle data and a faster-reacting watchdog, at the cost of radio airtime/power. |
| `WATCHDOG_RAMP_START_MS` | 175 | Time since the last valid packet before the receiver starts ramping throttle to idle | Must stay comfortably above the normal inter-packet gap (~12.5 ms at 80 Hz) or normal jitter will trigger false ramps. Lower = faster fail-safe reaction. |
| `WATCHDOG_FULL_IDLE_MS` | 600 | Time since the last valid packet before the receiver commits fully to idle and marks the link "recovering" | Must be greater than `WATCHDOG_RAMP_START_MS`. Too low risks committing to idle during a brief, recoverable glitch. |
| `RAMP_TO_IDLE_DURATION_MS` | 400 | Duration of the linear ramp from current throttle down to idle, once triggered | Shorter = snappier fail-safe but a more abrupt throttle cut; longer = gentler but leaves partial throttle applied longer during a real loss event. |
| `LINK_RESTORE_STABLE_MS` | 300 | After a loss event, how long the link must stay continuously valid before pilot throttle input is honored again | Higher = more confidence the link is genuinely back; lower = faster recovery but more exposure to a flickering link causing throttle hunting. |
| `MAX_THROTTLE_STEP_PER_TICK` | 6 (0–255 units) | Max throttle change per control tick, always — not just during recovery | Higher = snappier response; lower = smoother servo motion and less mechanical shock on the cable run. |
| `THROTTLE_DEADBAND` | 3 (0–255 units) | Handle-side hysteresis: the mapped trigger value must move at least this far before a new value is transmitted (0 and 255 always update) | Higher = less servo "hunting" from hand/engine vibration, at the cost of coarser resolution. |
| `IDLE_THROTTLE_VALUE` | 0 | What "idle" means on the 0–255 scale, matching your servo/cable mapping | The watchdog ramp target and the start gate below are both anchored to this — set it to your actual idle cable position. |
| `IDLE_THRESHOLD_FOR_START` | 15 (~6% of 0–255) | Throttle must be at/below this for a start request to be honored | Only checked at the `IDLE_SAFE → STARTING` transition itself — not re-checked once cranking, so the pot/trigger is free to move once a crank has begun. Higher tolerates a not-quite-zero idle reading; lower demands a stricter "really closed" throttle before allowing a crank. |
| `START_HOLD_REQUIRED_MS` | 600 | How long the start button must be held before a start request is sent | Higher reduces the chance of an accidental brush-start; lower is quicker to initiate cranking. |
| `KILL_DEBOUNCE_MS` | 30 | How long the kill line must read "kill" continuously before it latches | Kill is wired fail-safe, so this never defeats a genuine press or a severed wire — only delays recognizing it slightly. Higher rejects more vibration/contact-bounce glitches; lower reacts faster to a real kill. |
| `INPUT_DEBOUNCE_MS` | 20 | Debounce window for cruise + accessory inputs | Higher rejects more bounce; lower is more responsive but risks a single press registering as multiple toggles. |
| `CRUISE_DISENGAGE_THROTTLE_DELTA` | 10 (0–255 units) | How far the trigger must move above the frozen cruise setpoint before cruise disengages | Higher tolerates a light bump on the trigger while cruising; lower disengages cruise more readily on any throttle movement. |
| `CRUISE_REARM_THROTTLE_THRESHOLD` | 8 (0–255 units) | Third cruise-disengage path: counts as "neutral" (to start the hold below) and as "real input" (to actually cancel) — same value both directions, see ADR 0004's 2026-08-03 addendum for why | Higher makes both the neutral-detection and the retake-sensitivity more lenient; lower requires the pilot to release further and move more deliberately to trigger either half. |
| `CRUISE_IDLE_REARM_DELAY_MS` | 2000 | How long the trigger must sit continuously at/below `CRUISE_REARM_THROTTLE_THRESHOLD` (cruise engaged) before the next input above it cancels cruise | Any dip back above the threshold during the wait resets this timer. Higher makes the escape harder to trigger by accident (or on a longer intentional pause); lower makes it more readily available. |

### Manual crank bounds (`throttle_protocol.h`, receiver-only; see ADR 0007)

| Constant | Default | Controls | Tuning notes |
|---|---|---|---|
| `MAX_CRANK_MS` | 2000 | Hard backstop: a single crank energization can never exceed this, even if the button is held or `START_REQ` sticks asserted | Needs bench tuning against the actual Moster 185 cold-start behavior (see `docs/OPEN-ITEMS.md`) — long enough to reliably catch, short enough to protect the starter motor. |
| `CRANK_LOSS_ABORT_MS` | 175 | Stop cranking if no valid packet arrives for this long | Deliberately faster than the general watchdog thresholds above, since cranking blind on a dead link is worse than just holding throttle. Too low risks aborting a normal crank on a brief hiccup. |
| `STARTER_COOLDOWN_MS` | 3000 | After a *forced* crank stop (backstop or loss-abort — not a normal voluntary release) refuse a new crank this long | Higher gives more starter-motor protection between forced stops; lower allows a quicker retry once the fault clears. Never applies after a normal release. |

### Not tuning knobs

`PACKET_SYNC_BYTE`, the `CMD_FLAG_*` bit assignments, `PACKET_SIZE`, and
`PACKET_CRC_LEN` are protocol-format constants, not performance knobs —
both `handle` and `receiver` must agree on them exactly (see
`protocol-guardian`); there's no "desired performance" tradeoff to tune.

## Design Decisions Log
- **No radio-level ack** (`setAutoAck(false)`) — fixed-rate send + sequence number + watchdog covers command delivery without ack round-trip latency. Open question: revisit for kill specifically if confirmed-delivery matters more there.
- **CRC8/MAXIM chosen** over rolling custom checksum — small, well-tested, easy to hand-verify against known test vectors.
- **Servo spec** — pull force/travel must be measured across the full stroke (fish scale, not just one point) **through the full installed cable run** (remote mount adds Bowden friction, so measuring the bare throttle cable understates it) before ordering. Ballpark 15–25kg·cm digital metal-gear servo, continuous-duty rated.
- **nRF24L01+PA+LNA** (not bare module) — range margin needed given outdoor use, body/frame in the RF path. Buy from reputable supplier (Mouser/DigiKey), not cheap clones, given safety-critical context.

## Open Items / Not Yet Decided
- ~~What signal indicates "engine caught" to transition `STARTING` → `RUNNING`?~~ RESOLVED (ADR 0007): start is **manual** — the pilot is the catch sensor, so there is no `STARTING` → `RUNNING` transition and no tach in the controller.
- Actual measured distance/RF environment between handle and remote unit (through frame/cage/body) — determines whether PA+LNA gives enough margin
- Final servo selection pending cable force measurement
- Whether kill command should get an ack/confirmed-delivery path

## Toolchain
- STM32CubeIDE (includes CubeMX for peripheral config)
- ST-Link drivers (built into Nucleo boards)
- RF24 by TMRh20 (needs STM32 HAL port — original is Arduino-first)
- Git for version control
- Serial terminal (PuTTY or CubeIDE console) for debug prints
- Logic analyzer (cheap Saleae-compatible) for packet timing / PWM / kill relay verification
- Oscilloscope for servo PWM and kill line signal integrity checks

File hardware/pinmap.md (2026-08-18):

# Pin map / peripheral allocation

Derived from the firmware in `src/`. Target dev board: **Nucleo-32 STM32L432KC**
(one per unit). This is the blueprint you click into CubeMX.

> **How to read this:** allocation is by **peripheral + function** — that's what
> actually constrains the design. Exact pin numbers are assigned in **CubeMX**,
> which shows alternate-function conflicts live and prevents illegal
> combinations. The "suggested pin" column is a *starting point* to validate
> there, not a final assignment. SWD debug pins (PA13/PA14) are reserved by the
> Nucleo's on-board ST-Link — don't reuse them.

Both units share the SPI radio interface; they differ in the rest of their I/O.
Neither unit has any onboard battery sensing - see docs/OPEN-ITEMS.md
"Battery readout wiring" for why (standalone meters on the packs instead).

## Shared — nRF24L01+ radio (both units)

| Function | Peripheral | Suggested pin | Notes |
|---|---|---|---|
| SCK  | SPI1_SCK  | PA5 | SPI clock |
| MISO | SPI1_MISO | PA6 | |
| MOSI | SPI1_MOSI | PA7 | |
| CSN  | GPIO out  | PB0 | SPI chip-select (RF24 `csn`) |
| CE | GPIO out  | PB1 | RF24 chip-enable (TX/RX toggle) |
| IRQ  | GPIO in (EXTI) | PB2 | **Optional** — our code polls `radio.available()`; wire it only if you move to interrupt-driven RX |

nRF24L01+PA+LNA draws current bursts on TX (~100+ mA) — give it a solid 3.3 V
rail with local bulk + ceramic decoupling right at the module, or it browns out
mid-transmit.

## Handle unit (transmitter)

| Function | Peripheral | Suggested pin | Notes |
|---|---|---|---|
| Trigger position | ADC1_INx | PA0 | 12-bit, filtered in firmware. **Pull-down** so a broken trigger reads idle (ADR 0003) |
| Kill switch  | GPIO in | PA1 | **Fail-safe: normally-closed + pull-up**, open/broken = kill (ADR 0003) |
| Start button | GPIO in | PA2 | Normally-open, closed = start |
| Cruise button| GPIO in | PA3 | Normally-open, closed = press |
| Aux1 (lights)| GPIO in | PA8 | Normally-open, closed = on |
| Aux2 (smoke) | GPIO in | PA9 | Normally-open, closed = on |

Handle pin tally ≈ 6 (radio) + 6 (inputs) = **~12 of ~26 usable GPIO** → fits
the Nucleo-32 comfortably.

## Receiver unit (engine side)

| Function | Peripheral | Suggested pin | Notes |
|---|---|---|---|
| Servo signal | TIM2_CH1 (PWM) | PA0 | 50 Hz servo PWM; map 0–255 → pulse width |
| Kill driver | GPIO out | PB8 | Drives **relay/opto** that grounds the CDI kill wire (parallels mechanical kill). Energize-to-kill |
| Starter driver | GPIO out | PB9 | Drives **relay/opto** to the engine-battery starter solenoid coil (flyback diode across coil). Bounded pulse + cooldown in firmware |
| Aux1 out (lights) | GPIO out | PB10 | Via driver sized to the load |
| Aux2 out (smoke)  | GPIO out | PB11 | Via driver sized to the load |

Receiver pin tally ≈ 5–6 (radio) + 5 (servo/kill/starter/aux) = **~10–11
GPIO** → also fits the Nucleo-32. (No tach input — start is manual; see
ADR 0007.)

## Conclusion

**Nucleo-32 STM32L432KC is sufficient for both units.** No need to step up to a
Nucleo-64 on pin count. Bring-up order suggestion: radio link first (prove
handle→receiver packets), then servo, then the engine interface
(kill/starter) last — that one wants isolation hardware and the engine
present.

### Engine-interface hardware still to spec (see docs/OPEN-ITEMS.md)
- Isolation device choice for kill + starter (relay vs opto-SSR).
- CDI kill-wire voltage/behavior on the actual Moster 185.
- Starter solenoid coil voltage/current (sizes the driver + flyback).
- Servo selection (from cable-force measurement) → receiver power budget / BEC.

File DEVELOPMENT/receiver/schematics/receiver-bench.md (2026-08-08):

# Receiver bench schematic

No KiCad files yet (see `hardware/README.md` — that's where real schematics
will eventually live under CERN-OHL-S). This is a breadboard-level diagram
for the bench rig only, sufficient to wire it up; see `../docs/wiring.md`
for exact pin names and resistor values.

**Before wiring anything to `A4`/`A5`/`D4`/`D5`: cut solder bridges `SB16`
and `SB18` on the PCB.** They're closed by default on this board revision
and internally tie `PA6`↔`PB6` and `PA5`↔`PB7` together — see "Required
board mod" in `../docs/wiring.md` for the full explanation and how-to.

## Block diagram

Pin labels below are **Arduino header label / STM32 pin** — see
`../docs/wiring.md` for the full translation table and resistor-value
derivations. Renders natively on GitHub and in most Markdown viewers — no
extra software needed. (An ASCII version of this diagram lived here
previously; superseded by this Mermaid version, kept in git history if
ever needed.)

```mermaid
flowchart LR
    classDef power fill:#3a3a3a,stroke:#888,color:#fff
    classDef mcu fill:#1f4e79,stroke:#0d2b45,color:#fff
    classDef input fill:#2e7d32,stroke:#1b4d1e,color:#fff
    classDef output fill:#8a4b08,stroke:#5c3205,color:#fff
    classDef passive fill:#555,stroke:#222,color:#fff,stroke-dasharray: 3 3

    V33["3V3 rail"]:::power
    V5["5V rail"]:::power
    GND(["GND — common return"]):::power

    subgraph MCU["STM32L432KC Nucleo-32"]
        direction TB
        A1["A1 / PA1\nADC1_IN6"]:::mcu
        A2["A2 / PA3"]:::mcu
        A3["A3 / PA4"]:::mcu
        A4["A4 / PA5\nTIM2_CH1 PWM"]:::mcu
        A5["A5 / PA6"]:::mcu
        SEGPINS["A6, D9, D1/TX, D0/RX,\nD10, D2, D3\n(segs a-g)"]:::mcu
        D6["D6 / PB1"]:::mcu
        D12["D12 / PB4"]:::mcu
        D11["D11 / PB5"]:::mcu
        D5PIN["D5 / PB6"]:::mcu
        D4PIN["D4 / PB7"]:::mcu
    end

    POT["B103 pot\n10k linear, wiper center"]:::input
    BTN_START(("Start\nbutton")):::input
    BTN_CRUISE(("Cruise\nbutton")):::input
    BTN_KILL(("Kill\nbutton")):::input
    SERVO["SG90 servo"]:::output
    SEG["5611AH 7-seg\n(common-cathode)"]:::output
    BUZZ["Piezo buzzer"]:::output
    LED_G(("Green LED")):::output
    LED_R(("Red LED")):::output
    LED_Y(("Yellow LED")):::output
    LED_H(("Heartbeat LED")):::output
    R_G["220-330Ω"]:::passive
    R_R["220-330Ω"]:::passive
    R_Y["220-330Ω"]:::passive
    R_H["220-330Ω"]:::passive

    V33 --- POT
    GND --- POT
    POT -- wiper --> A1

    A2 -. "internal pull-up" .-> BTN_START --> GND
    A3 -. "internal pull-up" .-> BTN_CRUISE --> GND
    A5 -. "internal pull-up" .-> BTN_KILL --> GND

    A4 -- "orange: signal" --> SERVO
    V5 -- "red: V+" --> SERVO
    SERVO -- "brown: GND" --> GND

    SEGPINS -- "7x 150-220Ω\n(one per segment)" --> SEG
    SEG -- "common cathode" --> GND

    D6 -- click/pop --> BUZZ --> GND

    D12 --> R_G --> LED_G --> GND
    D11 --> R_R --> LED_R --> GND
    D5PIN --> R_Y --> LED_Y --> GND
    D4PIN --> R_H --> LED_H --> GND
```

**Remove the factory spare jumper cap between GND and D2 first** — it's
not functional, just a parking spot ST ships a spare clip in, but D2
(PA12) is segment f here and the jumper would short it to ground. See
`../docs/wiring.md`.

**Deliberately unused** (reserved by the board — see `../docs/wiring.md`):
A0/PA0 (board-locked MCO/clock-in), A7/PA2 (ST-Link VCP_TX), PA13/PA14
(SWD, not on this header), PA15 (ST-Link VCP_RX, not on this header),
D13/PB3 (on-board green LED, LD3), D7/D8 (PC14/PC15, crystal). PB2 doesn't
exist on this package at all and has no Arduino label.

`[R]` = one current-limiting resistor per segment/LED (~220–330Ω, see
`../docs/wiring.md`). All GND connections (buttons, pot, display common if
cathode, buzzer, LEDs, servo) share one breadboard ground rail tied to the
Nucleo's GND.

## 7-segment segment layout (for reference)

```
        aaaa
       f    b
       f    b
        gggg
       e    c
       e    c
        dddd
```

`bench_app.c`'s `DIGIT_SEGMENTS` table encodes which of a–g light for each
digit 0–9; the decimal point is left unconnected (not used for a 0–9
readout).

## Servo power note

Route the SG90's V+ from the Nucleo's `5V` header pin (USB-derived), not
`3V3`. If the board resets when the servo moves under load, switch the
servo to a separate 5V supply and keep grounds common — see
`../docs/wiring.md`.

## Power rail note

The pot/display-common rail is `3V3`, not `VIN` (VIN is a power *input* for
an external battery/adapter, not a usable output while running on USB) and
not `5V` (the pot feeds the ADC directly, which is only rated to ~3.3V) —
see "Power rails: 3V3 vs 5V vs VIN" in `../docs/wiring.md` for the full
reasoning.

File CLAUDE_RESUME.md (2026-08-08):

# Session resume notes

**Purpose of this file:** a snapshot of exactly where things stood at the end
of the last working session, for whoever (human or Claude) picks this back
up — likely once the radio hardware ordered below arrives. Read `CLAUDE.md`
first for the project itself; this file is just "where did we leave off."
Safe to delete/rewrite once it's stale — it's a handoff note, not permanent
documentation.

**As of:** 2026-08-02.

## Git state

Two branches, both pushed to `origin`:
- **`next`** — the integration branch. Everything below except the radio
  hardware-ordering docs lives here.
- **`feature/rf24-hal-port`** — radio bring-up work specifically, currently
  rebased on top of `next` (contains 3 commits on top: the radio bring-up
  plan doc and its two updates as hardware got ordered).

**Standing workflow policy** (also saved in Claude's memory, but noted here
in case a fresh session doesn't have that): whenever a commit lands directly
on `next` while `feature/rf24-hal-port` exists, rebase the feature branch
onto the updated `next` afterward. Rebasing rewrites the feature branch's
commits, so pushing that update needs `git push --force-with-lease` —
confirm with the user before force-pushing even though the rebase itself is
routine at this point.

## What's done

**Receiver bench rig** (`DEVELOPMENT/receiver/`) — complete and verified on
real hardware. Runs the actual `src/receiver/receiver_firmware.c` state
machine (via `#include`, one-line `millis()` fill-in only) on an STM32L432KC
Nucleo-32, fed by breadboard buttons/pot instead of the radio. Full
verification checklist passed 2026-08-01/08-02 — see
`DEVELOPMENT/receiver/docs/bench-behavior.md`. Required a real hardware mod
(SB16/SB18 solder bridges removed) — see "Gotchas" below.

**Receiver bench documentation** — wiring, CubeMX config, behavior spec, and
a Mermaid wiring diagram (`DEVELOPMENT/receiver/schematics/receiver-bench.md`,
renders natively on GitHub, no software needed) are all current and match
the built hardware.

**Design docs updated this session:**
- `docs/PROJECT_DESIGN.md` — added a full "Tunable Constants Reference"
  table (every `#define` in `throttle_protocol.h`/`battery_monitor.h`, what
  each one trades off); fixed a stale `RUNNING`-state reference.
- `docs/decisions/0001-no-radio-ack.md` — 2026-08-02 addendum: control
  uplink stays one-way/unacked (kill's own latch+resend plus the mechanical
  kill line already cover what ACK would add; auto-ack risks blocking sends
  longer under the ignition-EMI conditions ADR 0005 already flags as the
  dominant threat). A receiver→handle telemetry downlink is a legitimate
  future want (receiver battery/state currently have no path to the pilot)
  but deferred, and must stay structurally isolated from the control path
  if built.
- `docs/OPEN-ITEMS.md` updated to match.

**KiCad schematic** (`DEVELOPMENT/receiver/schematics/kicad/receiver-bench/`)
— electrically complete and verified, **0 ERC errors**. Built via a mix of
guided GUI walkthrough (user placed the potentiometer themselves, first
component, to validate the approach) and direct file authoring (everything
else — I don't have KiCad installed in this environment, so correctness was
checked by (a) the user running ERC in KiCad and reporting results back, and
(b) me writing small Python scripts to parse the file and verify pin↔label
coordinates programmatically rather than trusting my own arithmetic).
Contains: pot, 3 buttons, 7-segment display (7× LED+resistor, common
cathode), 4 status LEDs, buzzer, servo connector, and — as of the last
commit — the **real NUCLEO-L432KC board symbol** (SnapEDA import, both
CN3/CN4 header units placed as `U1`), with all 17 used MCU pins genuinely
wired to their matching peripheral-side labels (verified by script, not
eyeballing).

125 ERC warnings remain, all cosmetic/expected: off-grid coordinates
(doesn't affect correctness), simplified LED/switch/buzzer/connector symbol
graphics vs. KiCad's stock library art (deliberate — lower risk to
hand-author than matching exact stock geometry), and — before the MCU
symbol was wired in — single-use labels (mostly resolved now that each
label has a real MCU-pin endpoint too).

**Open/unresolved on the schematic:** the area around the MCU symbol's pins
is visually cluttered (three overlapping text elements per pin: KiCad's pin
name, pin number, and my added label, at only 2.54mm pin spacing). I
tried hiding the MCU's pin numbers as a fix; the user asked me to undo it
before deciding — **no layout fix has been agreed on yet**. Worth revisiting
if/when the user wants to actually read that part of the schematic
comfortably. Options not yet explored: longer pin-to-label wire stubs,
spacing pins out more (not possible — fixed by the real connector pinout),
or just accepting the clutter since electrical correctness doesn't depend
on it.

**Radio link — design decided, hardware partially arrived, nothing built.**
Bring-up plan, hardware rationale, and a real gotcha already caught
(STM32L432KC's *default* SPI1 pins are `PA5`/`PA6`/`PA7` — exactly the
SB16/SB18-bridged pins; use the `PB3`/`PB4`/`PB5` alternate mapping instead)
are fully documented in **`DEVELOPMENT/radio/README.md`** — read that file
first when resuming this thread, it has the current arrival status. As of
2026-08-03: the electrolytic + ceramic capacitor assortment kits and the
LONELY BINARY 8-channel 24MHz logic analyzer (pair with sigrok/PulseView,
not vendor software) have **arrived**; the 4× nRF24L01+PA+LNA modules
(Addicore) and the 2 additional Nucleo-32 L432KC boards (→ 4 total, only 1
has SB16/SB18 removed) are **still in transit**. Nothing to build yet until
those land, other than a quick PulseView smoke test on the logic analyzer.

## What's next (once hardware arrives)

Follow the bring-up order already written in `DEVELOPMENT/radio/README.md`:
1. Single board + single nRF24 module: confirm SPI works at all via a
   register read-back (e.g. `CONFIG`, datasheet default `0x08`). Use the
   logic analyzer on SCK/MOSI/MISO/CSN/CE to sanity-check against the
   datasheet timing diagrams.
2. **Decide**: adapt an existing STM32 port of TMRh20's RF24 library, or
   write a minimal custom driver against the datasheet (only need: fixed
   5-byte writes, poll-based `available()`/`read()`, no ack, no dynamic
   payload — see the doc for the specific tradeoff reasoning). Decide this
   once SPI is proven solid, not before.
3. Two boards + two modules: raw TX/RX smoke test, independent of either
   firmware file.
4. Only then: wire real `radio.*` calls into `handle_firmware.c` and
   `receiver_firmware.c` (currently fully commented-out stubs) and
   re-verify both bench rigs end-to-end over real radio.

Also still open, lower priority: the `DEVELOPMENT/transmitter/` bench rig is
still just a placeholder (deferred until the receiver rig proved out, which
it now has — could be picked up independently of the radio work).

## Gotchas worth remembering

- **SB16/SB18 solder bridges**: this Nucleo-32 L432KC revision ships with
  two SMD 0Ω resistors closed by default, internally tying `PA6`↔`PB6` and
  `PA5`↔`PB7`. Caused a multi-day "kill button reads stuck" mystery on the
  receiver bench rig. Removed on that one board only — the other 3 in
  inventory are still stock. Full removal procedure in
  `DEVELOPMENT/receiver/docs/wiring.md`. **This is exactly why the radio
  bring-up doc calls for the `PB3`/`PB4`/`PB5` SPI mapping** — the default
  SPI1 pins collide with these same bridged pins.
- **KiCad pin connectivity rule** (confirmed empirically, not from memory):
  a pin's `(at x y angle)` coordinate *is* its electrical connection point —
  `length`/`angle` only affect how the line is drawn, not where wires
  attach. Two pins/wire-ends at the exact same coordinate are connected
  without needing a wire between them; this is the trick used repeatedly
  (R→LED chains, the `PWR_FLAG` fix, tying the MCU's power pins into the
  existing GND/+3V3/+5V nets).
- **KiCad power-symbol nets merge by Value text, not by physical wire** —
  every `power:GND` instance (any number of them) is automatically the same
  global "GND" net just by having Value="GND"; a `PWR_FLAG`-style fix must
  still get its pin to the exact same coordinate as something already on
  that net (a T-junction via a separate wire segment silently failed ERC
  once already — see the `840725c` commit message for the full story).
- I don't have KiCad installed in this environment. Any further schematic
  changes need the same verify-by-having-the-user-run-ERC (or by scripting
  a coordinate-consistency check) loop used throughout this session — never
  trust a hand-authored `.kicad_sch` edit as correct without one or the
  other.

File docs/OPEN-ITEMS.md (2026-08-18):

# Open Items — action items & unresolved questions

Living tracker for this project. Add items as they come up; check them off when
resolved (and record *why* in `docs/decisions/` if it's a design decision worth
keeping). Grouped by area, most safety-relevant first.

Legend: `[ ]` open · `[x]` done · `[~]` in progress / partially done.

## Safety-critical / blocks flight-readiness

- [x] **Engine start / "caught" detection — resolved: MANUAL crank** (ADR 0007).
  Pilot holds the start button to crank and releases when the engine catches
  (they hear it + have a separate RPM gauge); no tach in the controller, no
  RPM-based `STARTING → RUNNING`. Crank is bounded by a loss-of-signal abort and
  a max-crank cap. This removed the tach subsystem and two non-fail-safe guards.
  (The project is still **not flight-ready** for other reasons — HAL bring-up,
  servo selection, hardware — see below.)
- [ ] **Bench-verify fail-safe kill.** Confirm on real hardware that a
  disconnected/broken kill wire reads as KILL (normally-closed + pull-up, open =
  HIGH = kill). Verify latch + `KILL_DEBOUNCE_MS` rejects vibration glitches but
  latches a genuine open. See `docs/decisions/0003-fail-safe-kill-polarity.md`.
- [ ] **Tune loss-of-signal watchdog** on the bench: `WATCHDOG_RAMP_START_MS`
  (175), `WATCHDOG_FULL_IDLE_MS` (600), `RAMP_TO_IDLE_DURATION_MS` (400),
  `LINK_RESTORE_STABLE_MS` (300). Current values are starting points.
- [x] ~~Aux-output policy during KILL / loss of signal (smoke force-gating)~~ —
  **resolved: no special policy, by deliberate choice.** AUX2 (smoke) was
  removed 2026-08-08 then restored 2026-08-09 once pins freed up elsewhere
  on the handle; revisiting this question on restore, the decision was to
  keep both AUX1 and AUX2 fully out of the kill/start/throttle state
  machine - `apply_aux_outputs` mirrors both flags unconditionally, same as
  before. Not an oversight - discussed and confirmed 2026-08-09.
- [ ] **Confirm mechanical kill wiring** is independent of the MCU and grounds
  the ignition line with zero power to electronics (backup for a dead radio).
- [x] ~~`RUNNING` → `IDLE_SAFE` restart policy~~ / ~~RPM START guard not fail-safe~~ —
  both **moot** under manual crank (ADR 0007): `STATE_RUNNING` no longer exists
  and the tach-dependent `rpm == 0` START guard is gone. The pilot can always
  re-crank (rising-edge + cooldown); protection against cranking an already-running
  engine now relies on pilot awareness + the starter's one-way clutch.
- [ ] **Tune crank bounds** on the bench: `MAX_CRANK_MS` (2000), `CRANK_LOSS_ABORT_MS`
  (175), `STARTER_COOLDOWN_MS` (3000). Confirm 2 s is enough for a cold Moster
  start — the pilot can release + re-press to keep cranking (only forced stops
  impose a cooldown). See ADR 0007.
- [ ] **Engine ignition EMI characterization (high priority).** With the receiver
  mounted in its real location next to the engine, sweep the full RPM range and
  log **consecutive** packet losses (not just loss rate) vs RPM. This is the
  failure mode most likely to trip the watchdog in flight: EMI-corrupted packets
  are discarded (safe), but sustained loss in an RPM band ramps throttle toward
  idle. ~14 consecutive losses (175 ms at 80 Hz) is the threshold-A budget. See
  `docs/decisions/0005-radio-choice-and-ignition-emi.md`.
- [ ] **Harden the kill line against EMI** — fail-safe NC kill runs near the CDI;
  coupled noise can pull it toward "kill". `KILL_DEBOUNCE_MS` rejects short
  spikes but not sustained EMI. Add ferrite chokes + twisted/shielded kill
  wiring and route away from the CDI/coil.
- [x] **Multi-unit isolation — prevent a foreign handle from controlling this
  receiver.** **Mechanism implemented 2026-08-14** (see below for the
  per-build discipline this still requires - that part is intentionally
  never "done"). Previously, every handle/receiver pair built from this
  code used the *identical* hardcoded nRF24 address (`PLACEHOLDER_ADDR` =
  `0xE7E7E7E7E7`) and channel (`PLACEHOLDER_RF_CHANNEL` = 76, see
  `src/common/nrf24.c`). Nothing in the packet (`sync`/`seq`/`throttle`/
  `flags`/`crc8`) carries any device identity, so two pilots' rigs within
  radio range were indistinguishable to each other's receivers — a
  receiver would accept a well-formed KILL/START/THROTTLE packet from
  *any* handle, not just its own. **Fix:** each manufactured handle+
  receiver pair gets a unique 5-byte nRF24 address, burned into both
  firmwares as a compile-time constant (like a serial number), replacing
  the placeholder — hardware-level address matching
  means a foreign packet is never even received by the MCU, no packet format
  change needed, no runtime pairing handshake (consistent with ADR 0001's
  no-ack rationale and this project's compile-time-constants-only
  philosophy). **Compile-time vs. a hardware DIP/rotary switch for setting
  the address in the field was explicitly weighed and decided against - see
  ADR 0009** (no spare pins on the handle to read a switch bank, and a
  physical switch is a real vibration-induced failure mode on this
  vehicle). Considered and set aside as the primary fix: per-pair channel
  (channel is a scarcer resource already earmarked for interference avoidance
  below — don't conflate the two; could still be a bonus secondary layer) and
  a device-ID in the 3 reserved `flags` bits (software-only check that runs
  after the packet is already received, and only 8 distinct values — not
  enough for a real fleet; leave those bits reserved). **Allocation scheme
  decided (recording only — not yet wired into firmware):** address =
  `0xE7 0xE7 0xE7 0xE7 <N>`, where `<N>` is a one-byte sequential unit number.
  `0x00` stays reserved as an "unassigned/placeholder" marker (so a unit still
  on `PLACEHOLDER_ADDR` is obviously unfinished) and `0xFF` is reserved for a
  possible future broadcast/test address; assignable range is `0x01`–`0xFE`
  (254 pairs). Numbers are assigned sequentially — never reused, even for a
  retired unit — and logged the moment they're assigned in the append-only
  `docs/UNIT-REGISTRY.md`. **Build-time mechanism (resolved):** a per-unit
  config header, `src/common/unit_config.h` — **tracked in git**, default
  `UNIT_NUMBER 0xFF` (deliberate unpaired bench/test build marker, not the
  reserved-but-refused `0x00`). `nrf24_handle_t` gained an `addr` field
  (same parameterized-not-hardcoded pattern as `hspi`/`ce_port`/etc.);
  `handle_app.c`/`prod_app.c` each build their 5-byte address from
  `UNIT_NRF24_ADDR_PREFIX` + `UNIT_NUMBER` and set it before calling
  `nrf24_init()`. `UNIT_NUMBER == 0x00` is a hard **compile-time `#error`**
  — the build itself refuses to produce a binary if the placeholder was
  never edited, not just a warning. Test builds (`UNIT_NUMBER == 0xFF`)
  also get a visual "this is not a paired unit" cue: both boards' status
  LED heartbeat renders **inverted** (mostly on with brief off blips,
  instead of mostly off with brief pulses) — see `UNIT_IS_TEST_BUILD` in
  `unit_config.h`.
- [ ] **⚠️ STANDING REMINDER — confirm `UNIT_NUMBER` before every real
  build. Intentionally never checked off.** Before flashing a unit meant
  to actually ship/fly as a real paired production unit, open
  `src/common/unit_config.h` and confirm `UNIT_NUMBER` is set to that
  pair's real assigned number from `docs/UNIT-REGISTRY.md` — **not** the
  tracked default (`0xFF`). The compile-time `#error` only catches the
  `0x00` case (file never touched at all); it cannot tell a genuine
  registry number apart from a left-at-`0xFF` bench build someone forgot
  to change before flashing real hardware. After flashing, revert the
  local edit (or otherwise make sure the real per-unit value never gets
  committed back to this file — see the comment in `unit_config.h`
  itself). This line should stay in this document, unchecked, permanently
  — it is a process discipline check, not a one-time task.

## Hardware decisions

- [ ] **Production PCB approach — Nucleo carrier board vs. bare STM32L432KC.**
  Need to decide, before ordering from PCBWay (or similar), whether production
  `handle-prod`/`receiver-prod` units keep the Nucleo-32 L432KC dev board
  soldered onto a custom carrier PCB that just breaks out its pins, or move to
  a from-scratch board built around the bare STM32L432KC chip. The bare-chip
  route drops dev-board cost/size but takes on power supervisor, crystal,
  ST-Link/debug header, and boot-mode strapping that the Nucleo currently
  provides for free (ADR 0006 chose the Nucleo for bring-up; this is the
  separate question of what production actually ships on).
- [ ] **KiCad schematics + ERC for production handle/receiver boards.** Only
  `receiver-bench` has a KiCad project today
  (`DEVELOPMENT/receiver/schematics/kicad/receiver-bench/`), and it's the
  bench rig, not `handle-prod`/`receiver-prod`. Once the Nucleo-carrier-vs-
  bare-chip decision above is made, need real schematics for both production
  boards and a KiCad ERC pass (unconnected pins, driver conflicts, missing
  power flags) before sending anything to PCBWay.
- [ ] **Production throttle (trigger) position sensor — rotary vs. linear,
  no leading candidate yet.** handle-prod's trigger is currently wired to a
  rotary pot (see `DEVELOPMENT/handle/handle-prod/docs/wiring.md` "Trigger"),
  but that's the bring-up part, not a production decision - open question is
  what sensor type actually ships in the production trigger mechanism: rotary
  pot (simplest, matches what's already proven on the bench) vs. linear/slide
  pot (may suit a different trigger-lever geometry or travel feel better).
  Need to figure out where to even start evaluating this.
  - **Follow-up once the real sensor is picked: recalibrate
    `read_throttle_position()`'s ADC-to-throttle mapping.** Bench-tested
    2026-08-15 on the current pot (after adding the RC anti-alias filter):
    raw ADC reads a clean, stable `0` at full release but only `~4030` at
    full pull, not the `4095` the mapping's `(smoothed * 255) / 4095`
    formula assumes - meaning full trigger pull currently commands ~98%
    throttle (`mapped` caps around 250), never a true 255, since the
    deadband's "always update at the rails" rule only forces an update at
    the literal 0/255 values. Don't fix this for the bench pot - not
    worth calibrating a part that isn't shipping. Once the real sensor is
    selected, measure *its* actual min/max on the bench and scale the
    mapping off those measured values instead of assuming rail-to-rail.
- [ ] **Handle kill switch is a bench-test stand-in, not the real part.**
  `handle-prod` is currently bench-testing with a normally-open switch
  bridged closed by a jumper wire, purely to unblock testing everything
  else. This project's fail-safe kill design (ADR 0003) requires a
  genuinely **normally-closed** switch/contact block - must be swapped
  before the handle is wired for real. See
  `DEVELOPMENT/handle/handle-prod/docs/wiring.md` "Kill switch".
- [~] **Servo selection** — measure pull force/travel across the full stroke
  **through the full installed cable run** (remote mount adds Bowden friction;
  the bare throttle cable understates it) before finalizing (~15–25 kg·cm digital
  metal-gear, continuous-duty ballpark). See ADR 0008. Fish scale arrived
  2026-08-16, force/travel measured on the existing handle cable (see below).
  **Prioritize speed/slew rate (deg/sec), second only to safety** - the
  current SG90 placeholder's own mechanical response is a likely major
  contributor to the throttle latency observed on the handle-prod bench
  test (2026-08-09; AUX1, which has no filtering/rate-limit pipeline,
  responded far faster than the servo-driven throttle). Pick a servo with
  a genuinely fast rated speed, not just adequate torque - a strong but
  slow servo would undermine responsiveness even with adequate pull force.
  **Update (2026-08-15):** ruled out software as the cause. The full
  handle→servo chain's timing budget (EMA settle ~65ms + receiver rate
  limiter ~42ms + 50Hz PWM update ~20ms) is well under 100ms, nowhere near
  the lag observed. Confirmed with the SG90 currently **unloaded** (no
  cable/spring attached): response is near-instant and moves at a steady
  speed to the target - not a torque-fighting-load deceleration, just the
  servo's own slew rate being slower than wanted. Since this is unloaded,
  it isn't even worst-case - the real installed cable+spring load will
  likely be at least this slow, probably slower.
  - [ ] **Fish-scale force + travel measurements taken (2026-08-16), on the
    existing handle-actuated cable — not yet through the future
    remote-mount Bowden run.** Per ADR 0008 this is a floor, not final:
    re-verify once the real cable routing exists, since Bowden friction
    isn't included here.
    - **Force:** ~2 lbf breakaway (start of cable movement), rising
      smoothly to ~5 lbf at 95-98% open, ~6 lbf at fully open. Budget
      7-8 lbf as a safety margin for spec'ing torque.
    - **Travel:** 1/4" slack at the lever before cable movement starts,
      then 7/8" of loaded cable travel to fully open - **1-1/8" (1.125")
      total linear pull** the servo mechanism must produce end to end.
    - **Torque/horn-arm sizing:** servo torque (kg·cm) = force (lbf) ×
      horn radius (in) × 1.152; rotation angle needed ≈ (throw ÷ radius)
      in radians. A 0.75"-1.0" horn radius needs only ~65-86° of
      rotation (comfortable margin below a standard ~120° usable range,
      room for end-stops) at a modest 6.9-9.2 kg·cm even at the 8 lbf
      margin figure - well under the original 15-25 kg·cm ballpark above.
      **Torque is no longer the binding constraint** - free to prioritize
      speed (deg/sec) per the update above.
    - **Candidates researched (2026-08-16).** First pass: Hitec
      **HS-5645MG** (12.1 kg·cm @ 6V, 0.18 sec/60° ≈ 333°/sec) and Hitec
      **D645MW** (11.4-13.0 kg·cm @ 6-7.4V, 0.17-0.20 sec/60° ≈ 300-353°/sec)
      - both explicitly marketed for throttle/control-surface (sustained
      holding) duty rather than RC-car burst duty, which is the key filter
      versus cheap generic "high torque" servos (e.g. MG996R/DS3218MG
      class) that are commonly reported to run hot/fail under continuous
      load. **Passed over after checking reviews** - HS-5645MG has
      recurring complaints of gear backlash/slop and centering drift (some
      out of the box) and eventual geartrain stripping; D645MW had thin
      review data plus one failure report (shock-load bashing use, not
      directly comparable, but not reassuring).
    - **Decided/ordered (2026-08-16): Savox SC-1256TGP** (the "Hybrid"
      case listing specifically - aluminum middle case + composite outer
      housing; note this exact listing had no reviews of its own yet at
      order time, distinct from the non-"Hybrid" SC-1256TGP listing whose
      reviews informed this pick - same titanium gears/coreless
      motor/torque-speed spec, so treated as the same core servo, but
      worth remembering this specific case variant is less proven).
      16 kg·cm @ 4.8V / 20 kg·cm @ 6V (comfortable margin above target,
      absorbs the not-yet-measured Bowden friction), 0.18 sec/60° @ 4.8V /
      0.15 sec/60° @ 6V (≈400°/sec - faster than both Hitec candidates),
      25T spline output. Fish-scale numbers still need re-verification
      through the real cable run once it exists (see above) before
      finalizing pulse-width mapping.
    - **Also ordered (2026-08-16): ProTek RC Dual Offset Heavy Duty
      Clamping Servo Horn (Standard, 25T)** - confirmed spline-matched to
      the SC-1256TGP. Dual-offset design gives multiple mounting-hole
      radii on one horn, letting the actual 0.75"-1.0" horn radius (see
      the torque/rotation-angle math above) be tuned empirically on the
      bench instead of committing to one fixed radius sight-unseen.
- [ ] **Remote servo mount + cable run (ADR 0008)** — the servo is frame-mounted,
  not on the engine, and drives the throttle via a push-pull/Bowden cable. To
  design: servo bracket, cable spec + routing (avoid tight bends), and slack/
  end-stops so full servo travel = full throttle stroke. `hardware/mechanical/`.
  **Cable on hand (2026-08-16): Sullivan Gold-N-Rod pushrod, 36" .032"
  cable w/ clevis (SUL507)** - flexible stranded-steel cable in an outer
  housing, the standard RC solution for a remote-servo-to-engine push-pull
  run. Not yet routed/installed - once the servo mount and routing are
  designed, re-measure fish-scale force through this actual cable run per
  ADR 0008 before finalizing the servo pulse-width mapping.
- [ ] **Confirm throttle return-to-idle spring** — the carb spring must reliably
  pull to idle when the servo is depowered/failed or the cable detaches (the
  mechanical fail-safe); verify the linkage can never jam open. May need a
  stiffer/different return spring depending on the selected servo's own
  unpowered ("limp") holding force - a spring sized for one servo's drag
  might not reliably overcome a different one's. Measure/select together
  with the servo, not independently.
- [ ] **Cable tolerance to engine movement** — the engine shifts on its rubber
  mounts relative to the frame; the cable run must flex without binding or
  shifting the throttle setpoint.
- [ ] **Vibration dampeners for receiver mounting (2026-08-14).** The receiver
  enclosure — and whatever battery ends up inside it, see the cell-format item
  below — needs isolation from engine vibration, not just a rigid mount to the
  frame. Evaluate dampening grommets/standoffs or an isolating mount plate
  between the receiver enclosure and the frame.
- [ ] **RF range test** — measure real handle↔receiver distance/reliability
  through frame/cage/body to confirm nRF24L01+PA+LNA gives enough margin. NOTE:
  this is a *separate* test from the engine-EMI RPM sweep above — different
  cause (path attenuation vs broadband ignition noise), different fix (band/power
  vs source suppression). Don't conflate the results.
- [ ] **Ignition EMI mitigations** — resistor plug cap/lead, receiver+antenna
  placement away from coil/CDI, ferrites on power/kill leads, CDI/coil grounding,
  receiver supply decoupling. Source suppression first (see ADR 0005).
- [ ] **Channel selection** — pick a channel clear of both local WiFi and the
  engine's worst harmonic bands; consider scanning on boot. Buy the module from a
  reputable supplier (not clones — mismatched PA/LNA erases the margin).
  (Scoped to interference avoidance only — see "Multi-unit isolation" above
  for preventing cross-talk between two pilots' rigs.)
- [x] **Receiver power source** — dedicated receiver battery (isolated from the
  engine's starter battery to avoid crank brown-out / EMI). See ADR 0005.
- [ ] **Servo power architecture (decision)** — servo transients are large; decide
  between (a) servo on the receiver pack via a dedicated BEC/regulator rail with
  bulk capacitance while MCU+radio sit on a cleaner rail, or (b) a separate servo
  battery. Sized after servo selection.
  **Current leaning (2026-08-09, not finalized):** receiver + servo on a
  **2S Li-ion pack** (7.4–8.4V) through a buck/BEC down to 5V for both the
  servo and the board; handle on a **single 1S Li-ion cell** (3.7–4.2V)
  through a boost module, since it has no servo and just needs clean
  3.3–5V logic power (cheap combined boost+USB-C-charge modules exist for
  exactly this). Cell **format** (cylindrical 18650 vs. pouch LiPo) is a
  separate, still-open decision — see the battery cell format item below.
  Real open sub-questions, not yet resolved:
  - Whether the Nucleo-32 L432KC's 5V/VIN pins tolerate direct external
    injection when not USB-powered — needs checking against the datasheet,
    not assumed.
  - BEC/boost current sizing depends on the still-unselected servo's
    stall/running current.
  - **Runtime target: ≥2 hours of continuous servo operation** — a real
    sizing constraint for both pack capacity and servo current draw once
    the servo is picked.
- [ ] **Battery cell format — cylindrical (18650) vs. pouch/soft-cell LiPo,
  still open (2026-08-14).** Cell count/voltage leaning is unchanged (1S
  handle, 2S receiver — see "Servo power architecture" above); the physical
  cell format is a separate, unresolved blocker before packs can be sourced
  or a battery compartment/mount designed for either unit.
  - **Cylindrical 18650**, swapped as loose individual cells — hard can gives
    better mechanical/thermal robustness than pouch, which matters more here
    given the receiver's engine-adjacent, high-vibration mount (see the
    vibration-dampener item above). Main risks: spring-contact reliability
    under vibration (needs contact preload + secondary retention, not just
    the spring), reverse-insertion risk (needs physical keying, not a
    warning label alone), and no cell-level protection unless using
    protected 18650s specifically.
  - **Pouch LiPo, 2-lead (no balance tap), one pack per cell** — soldered
    leads + a keyed connector (JST/XT) solve the contact-reliability and
    reverse-polarity risks cleanly, but pouch cells are more puncture/crush-
    sensitive and carry more thermal-runaway risk than a hard can, which
    weighs heavier here than in a typical RC application given the
    receiver's heat/vibration exposure near the engine. Would need
    reputable-brand packs (real datasheet, trustworthy mAh rating — matters
    for hitting the ≥2 hr runtime target) and likely a fireproof-bag storage/
    charging practice in production if this is the format chosen.
  - **Either format:** always charge each cell individually to full before
    combining in series — this is what avoids needing a 2S balance charger/
    tap at all, regardless of which format is picked. Packs/cells removable
    and charged externally either way — no onboard charge circuitry planned
    for either unit.
  - **Decision deferred; actual battery choice may still change.** Don't
    finalize the battery-compartment mechanical design or order production
    cells until this is resolved.
- [x] ~~Receiver battery chemistry/voltage~~ — **moot, 2026-08-17: all
  battery sensing removed project-wide** (see below). There is no longer a
  `RX_BATT` profile or `read_battery_mv()` to calibrate against a chosen
  pack - standalone battery meters on the packs are the only battery
  indication either board has now. Picking the receiver pack chemistry/
  voltage is still a real open question for power architecture (see
  "Servo power architecture" above), just no longer tied to any firmware
  calibration step.
- [ ] **Engine interface — isolation strategy (decision).** Recommend driving
  kill + starter through **relays or opto-isolated SSRs**, not bare MOSFETs, so
  receiver-ground stays isolated from the noisy engine-ground / starter domain.
  Confirm this before laying out the receiver board.
- [ ] **Kill driver** — relay/opto that grounds the CDI kill wire (parallels the
  independent mechanical kill; energize-to-kill, mechanical path is the zero-power
  fail-safe). Need the Moster 185 CDI kill-wire voltage/behavior to spec it.
- [ ] **Starter driver** — relay/opto to the engine-battery starter *solenoid*
  coil (flyback diode across coil); bounded pulse + cooldown in firmware. Need
  solenoid coil voltage/current.
- [x] ~~Tach-conditioning circuit~~ — **dropped**: no tach in the controller
  (manual crank, ADR 0007). Revisit only if a governor / rev-limiter / auto-idle
  feature is added later.
- [ ] **Connectors** — locking, vibration-rated (JST-SM minimum;
  Deutsch/Amphenol preferred).
- [x] ~~Battery readout wiring — 3/4-LED bar + piezo buzzer per side~~ —
  **superseded 2026-08-08, then removed entirely 2026-08-17.** The handle
  never had onboard battery sense (standalone battery meters on the packs
  themselves instead); the receiver briefly folded low-battery into its
  status LED's blink rate (`g_batt_low` scaling the heartbeat), but that
  read a real ADC pin (`BATT_SENSE`/`PA6`) that was never actually wired to
  a pack, so on the bench it just read the floating pin as "low" and ran
  the heartbeat at 2x speed - a confusing artifact, not a real feature.
  **Decision (2026-08-17): no battery indication of any kind on either
  board, ever** - not a bar, not a buzzer, not an LED blink-rate tell.
  `src/common/battery_monitor.h` and all `g_batt_low`/`read_battery_mv()`/
  `RX_BATT` code are deleted, not just unwired. Standalone battery meters
  on the packs (see the next item) are the only battery indication either
  unit has now, by design.
- [ ] **Battery capacity indicator modules ordered (2026-08-09).** Two
  kinds, one for each pack, both purely passive - 2-wire, connected straight
  across the battery terminals, no GPIO/ADC pins on either board and no
  firmware involvement at all:
  - Generic "1-8S universal" module: select the cell-count pad (S1-S8,
    solder-bridge one only) to match the pack; red 7-segment-style digits,
    4-level blue/green bar display. 3-34V working range, 5mA draw,
    -20-50°C. Not waterproof.
  - DGZZI 1S-specific module: fixed for a single cell (3.7-4.2V), 4-level
    red/orange/green bar (red ~5%, orange ~50%, green 75-100%). Also not
    waterproof.
  - Neither needs a decision before wiring - just connect to whichever pack
    ends up on each board once "Servo power architecture" above is settled.
- [ ] **Charging board compatibility (note for purchasing).** 1S and 2S
  packs need **different** charge modules - not interchangeable. A
  1S-rated board (e.g. common TP4056-style USB-C modules) caps out around
  4.2V and will undercharge a 2S pack; a 2S-rated charge board outputs
  ~8.4V and would overcharge a single cell. Series vs. parallel matters
  specifically for charging (parallel keeps it single-cell-equivalent
  voltage; series does not). For the 2S receiver pack, also get a board
  with a **balance** tap/connector - a plain series-only charger without
  balancing lets the two cells drift apart in capacity over many cycles,
  which shortens pack life and risks over-discharging one cell.
- [x] **Cruise / accessory switch wiring** — momentary pushbuttons for cruise,
  AUX1 (strobe), and AUX2 (smoke), all "closed = on" with pull-downs (kill
  and start are the pull-up exceptions). AUX1 is latched in firmware
  (press once for on, again for off); AUX2 stays purely momentary. All
  three confirmed working on handle-prod real hardware 2026-08-09. (AUX2
  was briefly removed 2026-08-08 for the handle's pin budget, restored
  2026-08-09 once pins freed up elsewhere on that board.)

## Firmware TODOs

- [x] Framework chosen: **STM32 HAL + CubeIDE**, Nucleo-32 L432KC dev board
  (ADR 0006). Arduino/STM32duino deliberately not used.
- [ ] Install STM32CubeIDE (bundles CubeMX); ST-Link is built into the Nucleo.
- [ ] Verify Nucleo-32 L432KC has enough pins/peripherals for both ends
  (pin-map exercise — handle I/O is fully known from firmware; receiver I/O
  partly depends on engine facts below). Bump to Nucleo-64 if short.
- [ ] Generate the two CubeMX projects and wire HAL peripheral inits
  (ADC, GPIO, TIM PWM, SPI) marked `/* fill in */`.
- [ ] RF24 HAL port (TMRh20 is Arduino-first) for both ends — stays on the
  critical path given the HAL choice.
- [ ] Servo PWM mapping: 0–255 throttle → pulse-width for the chosen servo.
  `DEVELOPMENT/receiver/receiver-prod/`'s TIM2 (50 Hz servo PWM, `PA5`) is
  currently set up for a **placeholder SG90 micro servo** (bench-test only,
  not the final actuator): Prescaler=31, Period=19999 (these two just set the
  50 Hz frame rate and should hold for any standard-protocol servo,
  metal-gear included), Pulse=1500 (1.5 ms, SG90 center). Once the real servo
  is selected (see "Servo selection" above), revisit the pulse-width
  min/max mapped to full-closed/full-open throttle — likely just a firmware
  constant change, not a CubeMX regeneration, unless the new servo uses a
  non-standard control protocol.
- [~] **Trigger-ADC anti-alias + oversampling.** The trigger is sampled at 80 Hz,
  so hand/engine vibration above ~40 Hz **aliases** and no software filter can
  remove it. Needs both a hardware and a firmware half - the EMA + deadband/
  hysteresis (`THROTTLE_DEADBAND`) already in the handle and the receiver's
  servo rate-limiter all sit *after* sampling, so none of them can fix
  aliased noise; it has to be addressed at the sampling stage itself.
  - **Firmware half done (2026-08-14):** `read_throttle_raw_oversampled()`
    in `src/handle/handle_firmware.c` averages `TRIGGER_OVERSAMPLE_COUNT`
    (8, `src/common/throttle_protocol.h`) back-to-back raw ADC conversions
    into one sample before the EMA ever sees it. Helps on its own, but is
    not a substitute for the hardware half below - oversampling alone
    can't undo aliasing that already happened in the analog domain.
  - **Hardware half wired (2026-08-14), ceramic + wiring-bug fix
    (2026-08-17):** an **RC low-pass on the ADC input**
    (`PA5`/`TRIGGER_ADC` on `handle-prod`) as the actual anti-alias
    filter. **R=1kΩ, C=2.2µF ceramic (50V, `225`) → cutoff ≈72Hz** -
    deliberately chosen below the original ~100Hz estimate: comfortably
    below the Moster 185's ~120-130Hz fundamental vibration frequency at
    max RPM (more attenuation margin there), while still far above any
    realistic hand-trigger input speed, so nothing is lost on the input
    side. R1 goes in series between the pot wiper and the filter node;
    C1 and the existing 100kΩ fail-safe pull-down both connect from that
    same node to GND, in parallel with each other, and that node is also
    where the pin taps in - see
    `DEVELOPMENT/handle/handle-prod/docs/wiring.md` "Trigger" for the
    full writeup and diagram. **Must be paired with a longer ADC sampling
    time** in CubeMX for the trigger channel (currently
    `ADC_SAMPLETIME_2CYCLES_5`, sized for ~zero source impedance) - the
    series R needs a much longer sample window for the ADC's
    sample-and-hold capacitor to charge fully, or readings silently read
    low. Treat the RC filter and the sampling-time change as one combined
    change, and verify a known trigger position (e.g. full release ≈ 0)
    reads correctly afterward.
  - [x] **Ceramic cap swap done (2026-08-17).** Replaced the original
    2.2µF electrolytic with a 2.2µF ceramic (`225`, from a 24-value 50V
    kit that finally arrived) - lower leakage/ESR, and genuinely
    unpolarized (no reverse-wiring risk) rather than "polarity is
    well-defined here so it's fine," which the electrolytic relied on.
    Same 1kΩ R1, same node, so the loading/cutoff math is unchanged.
  - [x] **Wiring bug found + fixed (2026-08-17): R1 was on the wrong side
    of the filter node since the original 2026-08-14 install.** Actual
    wiring was `wiper → [node: C1, 100kΩ pull-down] → R1 → pin` instead of
    the intended `wiper → R1 → [node: C1, 100kΩ pull-down, pin]`. Caught
    by comparing the physical breadboard against
    `trigger-filter-wiring.html` while doing the ceramic swap. Two
    consequences, full detail in `wiring.md`'s 2026-08-17 note:
    - The calculated 72Hz cutoff was never actually in effect - the real
      filter resistance was the pot's own (position-dependent) wiper
      resistance, not the fixed 1kΩ. Bench data collected in this window
      (e.g. the 2026-08-15 held-position jitter check) only validated
      static-position noise, not the filter's frequency response, so it
      didn't catch this.
    - The wiper-wire fail-safe was **not** compromised (pull-down still
      correctly forced the pin to 0V if the wiper wire broke), but an
      **R1 open-failure would have left the pin floating** with no
      fail-safe path - a real gap in a vibration-heavy environment. Fixed
      topology protects against both failure modes now.
    - **Re-verification still needed:** the bench jitter check (breakpoint
      on `read_throttle_position()`'s `return last_out;`, held positions)
      should be re-run as a basic regression check, but real validation of
      the filter's actual frequency response requires vibration - i.e.
      the engine, not yet available. Tracked as its own follow-up below.
  - [ ] **Re-verify the trigger filter under real vibration once the
    engine is available (2026-08-17).** Now that the wiring is corrected,
    this is the first time the filter can be meaningfully verified at all
    - prior bench checks only ever confirmed held-position stability, not
    frequency response. Fold into the existing engine-availability bench
    items below (loss-of-signal watchdog EMI sweep, etc.) rather than
    treating as a separate bench session.
  - [x] **Tuned the EMA `FILTER_SHIFT` and `THROTTLE_DEADBAND` on real
    hardware (2026-08-15, `feature/ema-deadband-tuning`).** With the RC
    filter + oversampling now doing the primary anti-alias job upstream,
    relaxed both: `FILTER_SHIFT` 2→1 (EMA settling ~130ms→~65ms) and
    `THROTTLE_DEADBAND` 3→1 (finer resolution, justified by the near-zero
    jitter measured at held trigger positions in the bench debugger data).
    Small, borderline-perceptible improvement on the bench - most of the
    remaining latency turned out to be the SG90 test servo's own slew
    rate, not filtering; see "Servo selection" below. (Raised by
    instructor feedback on servo-from-analog control: debounce, damping,
    hysteresis.)
- [ ] Generate the STM32CubeIDE projects (none committed yet).
- [x] ~~Open question: does **kill** warrant a confirmed-delivery/ack path~~ —
  **resolved: no.** Kill's latch+resend already survives arbitrary packet
  loss on its own, and a fully-dead link (the only case ACK could help) is
  already covered by the independent mechanical kill line. Auto-ack also
  risks blocking sends longer exactly under the ignition-EMI condition ADR
  0005 already flags as the dominant threat. See the 2026-08-02 addendum in
  `docs/decisions/0001-no-radio-ack.md`.
- [ ] **Telemetry downlink (receiver → handle), deferred.** Receiver battery
  level and receiver state currently have no path to the pilot at all — worth
  building eventually, but as a separate, strictly one-way, structurally
  isolated feature (own packet type/pipe, never able to delay or gate a
  control packet), after the primary control link is working. Not a
  flight-readiness blocker on its own. **When built, the handle should show**
  its own battery level side by side with the receiver's (telemetered), plus
  receiver system status (cranking/idle-armed/killed) — see the 2026-08-08
  addendum in `docs/decisions/0001-no-radio-ack.md` for the full reasoning
  and transport constraints.
- [ ] Low priority: evaluate **CRC8 → CRC16** given the EMI environment (packet
  5→6 bytes). CRC8 is defensible today — sync + seq filtering plus throttle
  rate-limiting contain any single false-accept — but worth revisiting if the
  RPM-sweep test shows heavy corruption. See ADR 0005.

## Licensing / legal

- [x] Firmware licensed GPL-3.0-or-later (`LICENSE`, SPDX headers).
- [ ] Add hardware `LICENSE` (CERN-OHL-S) once schematic/PCB files exist.
- [x] Loud safety disclaimer + no-liability-for-forks note in `README.md`.
- [ ] Optional: brief consult with a lawyer familiar with open safety-critical
  hardware before wide distribution / before anyone flies it.

## Docs / process

- [x] Seed architecture decision records in `docs/decisions/`.
- [ ] Keep `src/common/` byte-identical assumption enforced (see the
  `protocol-guardian` subagent in `.claude/agents/`).

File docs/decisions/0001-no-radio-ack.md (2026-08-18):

# 0001 — No radio-level acknowledgement

**Status:** accepted · **Date:** 2026

## Decision

Run the nRF24L01+ link with `setAutoAck(false)`: the handle transmits fixed-rate
(80 Hz), one-way, and the receiver never acks at the radio layer.

## Why
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

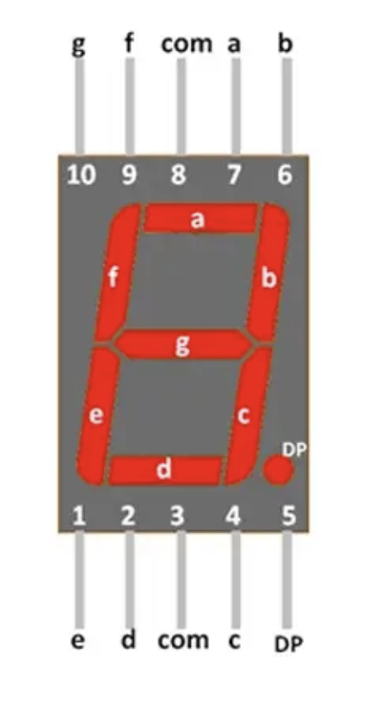
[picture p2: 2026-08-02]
docs/5611AH_pinout_7-segment_display.png

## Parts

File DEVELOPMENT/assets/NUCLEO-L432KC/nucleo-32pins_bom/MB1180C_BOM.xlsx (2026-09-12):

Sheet: BOM Report
Bill of Materials
Source Data From: |  | MB1180.PrjPCB
Project: |  | MB1180.PrjPCB
Variant: |  | None
Version | C-09
Select MCU Reference in follow list:
L412KB
Board name:NUCLEO-L412KB
Comment | Designator | Footprint | Quantity | Assembly | Ordered by | Comments | Description | Manufacturer 1 | Part#1 | Manufacturer 2 | Part#2 | ECCN US | ECCN EU | Info source
KSS221G | B1 | KSS221G | 1 |  | Subcon |  | tact switch,horizontal,TD-26E,SMT | Qiaod | TD-26E |  |  | NA | NA
100nF | C1, C2, C4, C5, C7, C8, C10, C11, C15, C19, C23, C24 | 0603C | 12 |  | Subcon |  | Capacitor,100nF,10%,16V,X7R,0603,YAGEO | YAGEO | CC0603KRX7R7BB104 |  |  | NA | NA
20pF[N/A] | C3 | 0603C | 1 | [N/A] | Subcon |  |  |  |  |  |  | NA | NA
4.7uF | C6 | 0603C | 1 |  | Subcon |  | Capacitor,4.7uF,16V, X5R,10%,0603 | YAGEO | CC0603KRX5R7BB475 |  |  | NA | NA
1uF_X5R_0603 | C9, C14, C16, C18 | 0603C | 4 |  | Subcon |  | Capacitor,1uF,0603,16V,10%,X5R,YAGEO | YAGEO | CC0603KRX5R7BB105 |  |  | NA | NA
4.3pF | C12, C13 | 0603C | 2 |  | Subcon |  | Capacitor,4.3pF,±0.25pF,50V,COG,0603,0603CG4R3C500NT | YAGEO | 0603CG4R3C500NT |  |  | NA | NA
10nF_X7R_0603 | C17 | 0603C | 1 |  | Subcon |  | Capacitor,10nF,0603,50V,10%,X7R,YAGEO; | YAGEO | CC0603KRX7R9BB103 |  |  | NA | NA
10pF | C20, C21 | 0603C | 2 |  | Subcon |  | Capacitor,10pF,5%,50V,NPO,0603,YAGEO | YAGEO | CC0603JRNPO9BN100 |  |  | NA | NA
10uF(25V) | C22 | TAN_B | 1 |  | Subcon |  | TAN Capacitor,10uF,10%,25V,B type,AVX | AVX | TAJB106K025RNJ |  |  | NA | NA
10uF | C25 | TAN_A | 1 |  | Subcon |  | TAN Capacitor,10uF,10%,16V,A type,AVX | AVX | TAJA106K016R |  |  | NA | NA
1050170001 | CN1 | MOLEX_1051640001 | 1 |  | Subcon |  | USB connector,1050170001,B type,SMT,MOLEX | MOLEX | 1050170001 |  |  | NA | NA
[N/A] | CN2 | HDR1x5-P254-V-M | 1 | [N/A] | Subcon |  |  |  |  |  |  | NA | NA
Header 15X1 | CN3, CN4 | PH2541-15-SPGRH-6-3_V | 2 |  | Subcon |  | Pin header,PH2.54*2.5 1*15P DIP 180°L=14.5/6.0/6.0 PA6T,1U” | ATOM | PH254015B-09303 |  |  | NA | NA
BAT60JFILM | D1, D2, D4 | SOD-323 | 3 |  | STM |  | Diode,BAT60JFILM,SOD-323,STM | STM | BAT60JFILM |  |  | EAR99 | NEC | TCDR
STPS2L30A | D3 | SMA | 1 |  | STM |  | Diode,STPS2L30A,2A,30V,SMA | STM | STPS2L30A |  |  | EAR99 | NEC | TCDR
PH127H10102JNG-2/3/1.5 | JP1 | 1*2P SMD | 1 |  |  | 1.27mm SMD male connector | Pin header,1.27mm,1*2P,horizontal ,PH127H10102JNG-2/3/1.5 | PCE | PH127H10102JNG-2/3/1.5 |  |  | NA | NA
BEAD | L1 | 0603L | 1 |  | Subcon |  | bead,600R,350mA,0603,FCM1608KF-601T05,Tai-tech | Tai-tech | FCM1608KF-601T05 |  |  | NA | NA
LD_BICOLOR_CMS | LD1 | HSMF-A201 | 1 |  | Subcon |  | LED,red-green bi-color,3.2 mm x 2.8 mm,LE-RGW35280,SMT, | everluck | LE-RGW35280 |  |  | NA | NA
RED | LD2 | KING-LED0603-25-RED_V | 1 |  | Subcon |  | LED,red,0603 | everlight | 19-217/R6C-AL1M2VY/3T |  |  | NA | NA
Green | LD3 | KING-LED0603-25-GREEN_V | 1 |  | Subcon |  | LED,green,0603 | everlight | 19-213SY6C/S530-E2/TR8LED |  |  | NA | NA
1K5 | R1 | 0603R | 1 |  | Subcon |  | Resistor,1.5K,0603,1%,YAGEO | YAGEO | RC0603FR-071K5L |  |  | NA | NA
100K | R2, R6, R9 | 0603R | 3 |  | Subcon |  | Resistor,100K,0603,1% | YAGEO | RC0603FR-07100KL |  |  | NA | NA
36K | R3 | 0603R | 1 |  | Subcon |  | Resistor,36K,0603,1% | YAGEO | RC0603FR-0736KL |  |  | NA | NA
10K | R4, R15, R16, R21 | 0603R | 4 |  | Subcon |  | Resistor,10K,0603,1% | YAGEO | RC0603FR-0710KL |  |  | NA | NA
100 | R5, R8, R18, R19, R20 | 0603R | 5 |  | Subcon |  | Resistor,100R,0603,1% | YAGEO | RC0603FR-07100RL |  |  | NA | NA
2.7K | R7 | 0603R | 1 |  | Subcon |  | Resistor,2.7K,0603,1%,YAGEO | YAGEO | RC0603FR-072K7L |  |  | NA | NA
4K7 | R10, R12, R14 | 0603R | 3 |  | Subcon |  | Resistor,4.7K,0603,1% | YAGEO | RC0603FR-074K7L |  |  | NA | NA
2K7 | R11 | 0603R | 1 |  | Subcon |  | Resistor,2.7K,0603,1%,YAGEO | YAGEO | RC0603FR-072K7L |  |  | NA | NA
10K[N/A] | R13 | 0603R | 1 | [N/A] | Subcon |  |  |  |  |  |  | NA | NA
0 | R17 | 0603R | 1 |  | Subcon |  | Resistor,0R,0603,5%,YAGEO | YAGEO | RC0603JR-070RL |  |  | NA | NA
1K | R22 | 0603R | 1 |  | Subcon |  | Resistor,1K,0603,1%,YAGEO | YAGEO | RC0603FR-071KL |  |  | NA | NA
510 | R23 | 0603R | 1 |  | Subcon |  | Resistor,510R,0603,1% | YAGEO | RC0603FR-07510RL |  |  | NA | NA
Circuit Breaker (open) | SB1, SB4, SB17 | SB_0603 | 5 | [N/A] | Subcon |  |  |  |  |  |  | NA | NA
Circuit Breaker (close) | SB2, SB3, SB9, SB10, SB11, SB12, SB13, SB14, SB15, SB16, SB18 | SB_0603 | 9 |  | Subcon |  | Resistor,0R,0603,5%,YAGEO | YAGEO | RC0603JR-070RL |  |  | NA | NA
Circuit Breaker | SB6, SB8 | SB_0603 | 2 | open | Subcon |  | Resistor,0R,0603,5%,YAGEO | YAGEO | RC0603JR-070RL |  |  | NA | NA
Circuit Breaker | SB5, SB7 | SB_0603 | 2 | close | Subcon |  | Resistor,0R,0603,6%,YAGEO | YAGEO | RC0603JR-070RL |  |  | NA | NA
9013 | T1 | SOT23-3 | 1 |  | Subcon |  | Transistor,MMBT9013,SOT-23,ST | ST | MMBT9013 |  |  | EAR99 | NEC
ST890CDR | U1 | SO-8 | 1 |  | STM |  | IC PWR SWITCH MOSFET P-CH 8-SOIC,ST890CDR, | STM | ST890CDR |  |  | EAR99 | NEC | MB1162
STM32L412KBU6U | U2 | UFQFPN32 | 1 |  | STM |  | IC MCU 32BIT 32UFQFPN,STM32L412KBU6U | STM | STM32L412KBU6U |  |  | 3A991A2 | NEC | TCDR
LD39050PU33R | U3 | DFN6 | 1 |  | STM |  | LDO Regulator Pos 3.3V 0.5A,LD39050PU33R,DFN6 | STM | LD39050PU33R |  |  | EAR99 | NEC | MB1136
LD3985M33R | U4 | SOT23-5L | 1 |  | STM |  | LDO Regulator Pos 3.3V 0.55A 5-Pin SOT-23 ,LD3985M33R | STM | LD3985M33R |  |  | EAR99 | NEC | MB1137
STM32F103CBT6 | U5 | LQFP_48 | 1 |  | STM |  | MCU 32-bit STM32F1 ARM Cortex M3 RISC 128KB Flash 2.5V/3.3V ,STM32F103CBT6, LQFP-48 | STM | STM32F103CBT6 |  |  | 3A991A2 | NEC | MB1138
LD1117S50TR | U6 | SOT-223 | 1 |  | STM |  | LDO Regulator Pos 5V 1.3A 4-Pin(3+Tab) SOT-223 T/R,LD1117S50TR, | STM | LD1117S50TR |  |  | EAR99 | NEC | MB1139
NX3215SA-32.768K-EXS00A-MU00525 | X1 | XTAL_2SM_3R2X1R5 | 1 |  | STM |  | Crystal,NX3215SA-32.768KHZ-EXS00A-MU00525,32.768K,6PF,3215,20PPM | NDK | NX3215SA-32.768KHZ-EXS00A-MU00525 |  |  | NA | NA
NX3225GD 8MHz EXS00A-CG04874 | X2 | X53T | 1 |  | STM |  | Crystal,NX3225GD-8MHz-EXS00A-CG04874,8MHz,8pF,SMT | NDK | NX3225GD-8MHz-EXS00A-CG04874 |  |  | NA | NA
MJ127H30102SPG |  |  | 1 |  | Subcon | Jumper Hat | Jumper Hat,1.27mm | PCE | MJ127H30102SPG |  |  | NA | NA
Jumper |  |  | 1 |  | Subcon | 2.54mm Jumper Hat mounted on CN3 pin 4 & 5 |  |  |  |  |  | NA | NA
Sticker1 = ES |  |  | 1 | only for prototype board | Subcon | Placed on U2 footprint (top side on the right of St-link connector)
Sticker2 = L412KB |  |  | 1 |  | Subcon | placed on USB connector for sale type sticker
Approved |  | Notes

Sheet: Project Information
Project Full Path | C:\X_ezhong\ezhong_view_2\vob\mcd_eval\nucleo\boards\mb1180_32pins\schematics\MB1180.PrjPCB
Project Filename | MB1180.PrjPCB
Variant Name | None
Data-Source Filename | MB1180.PrjPCB
Data-Source Full Path | C:\X_ezhong\ezhong_view_2\vob\mcd_eval\nucleo\boards\mb1180_32pins\schematics\MB1180.PrjPCB
Title | Bill of Materials For Project [MB1180.PrjPCB] (No PCB Document Selected)
Total Quantity | 86
Report Time | 2:22:29 PM
Report Date | 1/22/2015
Report Date & Tine | 1/22/2015 2:22:29 PM
Output Name | Bill of Materials
Output Type | BOM_PartType
Output Generator Name | ReportComponents
Output Generator Description | Component Reports

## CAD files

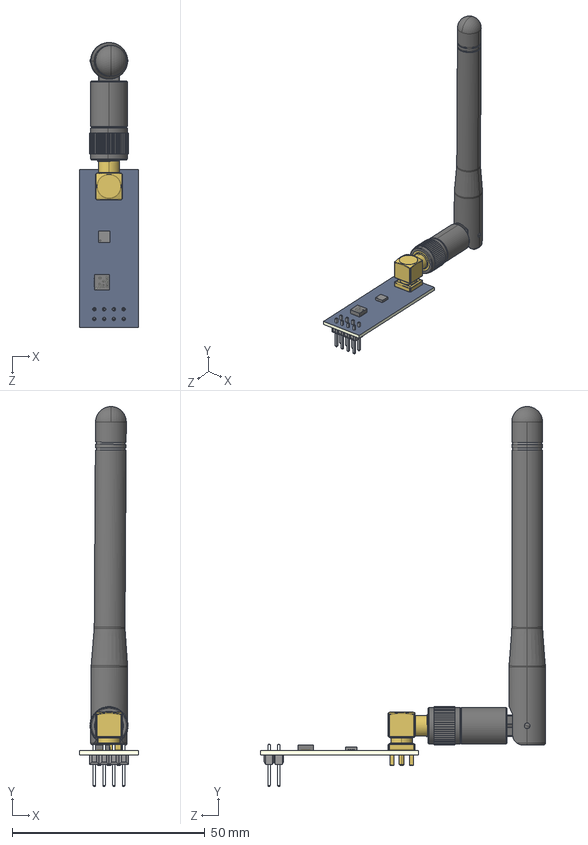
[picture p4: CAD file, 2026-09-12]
DEVELOPMENT/assets/nRF24L01+/NRF24l01_with_antenna.STEP
15.2 x 98.7 x 74.0 mm
NRF24L01_PCB
male header x 8
NRF24L01_SMA-angled
NRF24L01-CHIP-NRF___ _________
User Library-QFN-16_3x3_1
User Library-QFN-16_3x3_2
User Library-QFN-16_3x3_3
User Library-QFN-16_3x3_4
User Library-QFN-16_3x3_5
User Library-QFN-16_3x3_6
User Library-QFN-16_3x3_7
User Library-QFN-16_3x3_8
User Library-QFN-16_3x3_9
User Library-QFN-16_3x3_10
User Library-QFN-16_3x3_11
User Library-QFN-16_3x3_12
User Library-QFN-16_3x3_13
User Library-QFN-16_3x3_14
User Library-QFN-16_3x3_15
User Library-QFN-16_3x3_16
User Library-QFN-16_3x3_17
User Library-QFN-16_3x3_18
Bottom_Radio_Antenna_DＧaut
Top_Radio_Antenna_DＧaut
Screw_Radio_Antenna_DＧaut
Insert_Radio_Antenna_DＧaut
Pin_Radio_Antenna_DＧaut x 2
Wire_Top_Radio_Antenna_DＧaut
Wire_Radio_Antenna_DＧaut

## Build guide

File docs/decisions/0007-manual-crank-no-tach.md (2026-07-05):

# 0007 — Manual cranking (no tach in the controller)

**Status:** accepted (supersedes the RPM-based engine-caught approach) · **Date:** 2026

## Decision

Electric start is **manual**: the receiver energizes the starter while the pilot
holds the (hold-confirmed) start button and releases it when the engine catches.
The pilot — who hears the engine and already runs a **separate RPM gauge** — is
the "engine caught" sensor. There is **no tach wired into the receiver** and no
RPM-based `STARTING → RUNNING` transition.

## Why

- A paramotor electric start is normally a held-button affair; the human is a
  perfectly good catch sensor, and the pilot's existing RPM readout means a tach
  into the controller adds no information they lack.
- Removes a whole EMI-coupled subsystem: the plug-lead pickup shares the
  ignition's broadband noise (ADR 0005), plus a tach-conditioning circuit.
- Removes two guards that were never fail-safe: RPM-based catch detection and the
  `rpm == 0` "don't crank a turning engine" gate — both failed *permissive* on a
  tach fault or an MCU reset.
- Simpler receiver state machine (`STATE_RUNNING` dropped).

## How the crank is bounded (it can't run away)

- **Rising-edge start** — must release and re-press to re-crank; after a forced
  cutoff, holding the button does nothing.
- **`CRANK_LOSS_ABORT_MS` (~175 ms)** — stop if the link goes silent mid-crank
  (can't command kill wirelessly while blind).
- **`MAX_CRANK_MS` (~2 s)** — hard backstop even if the button is held or
  `START_REQ` sticks asserted.
- **`STARTER_COOLDOWN_MS`** applies only after a *forced* stop; a normal release
  imposes no cooldown, so re-cranking a stubborn cold engine is instant.
- Plus the existing kill-first ordering and the main-loop safety net that forces
  the starter off whenever `state != STARTING`.

## Tradeoffs accepted

- No automatic starter release on catch — the pilot releases (the starter's
  one-way clutch and the max-crank cap mitigate over-cranking).
- No firmware protection against cranking an already-running engine (e.g. after a
  pull start) — relies on pilot awareness + the starter clutch.

## Reconsider if

We later want a **governor / rev-limiter / auto-idle-on-engine-death** — those
need RPM the pilot can't provide and would reintroduce a (well-conditioned) tach
input. Deferred; not needed for v1.

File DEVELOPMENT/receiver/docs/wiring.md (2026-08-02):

# Wiring — receiver bench rig

Board: **STM32L432KC Nucleo-32** (UFQFPN32 package — only 26 usable GPIOs
total). This board's physical header uses **Arduino Nano-style silkscreen
labels** (`A0`–`A7`, `D0`–`D13`, `3V3`, `5V`, `VIN`, `GND`, ...), not the
STM32 port/pin names (`PA0`, `PB3`, ...) used everywhere else in this repo
— the two don't run in any obvious order relative to each other. Every pin
below is given as **Arduino label (STM32 name)** so you can wire directly
from your board's silkscreen without translating.

This mapping is ST's official one (UM2179, "Arduino Nano connectors on
NUCLEO-L432KC" table), cross-checked against the board-lock data below —
`A0`↔`PA0` (locked to MCO), `A7`↔`PA2` (locked to VCP_TX), and `D13`↔`PB3`
(the on-board LED) all line up exactly with what we already knew about
those three pins, which is a solid consistency check on the source.

| Arduino label | STM32 pin | Arduino label | STM32 pin |
|---|---|---|---|
| A0 | PA0 | D0/RX | PA10 |
| A1 | PA1 | D1/TX | PA9 |
| A2 | PA3 | D2 | PA12 |
| A3 | PA4 | D3 | PB0 |
| A4 | PA5 | D4 | PB7 |
| A5 | PA6 | D5 | PB6 |
| A6 | PA7 | D6 | PB1 |
| A7 | PA2 | D7 | PC14 |
| | | D8 | PC15 |
| | | D9 | PA8 |
| | | D10 | PA11 |
| | | D11 | PB5 |
| | | D12 | PB4 |
| | | D13 | PB3 |

Plus `3V3`, `5V`, `VIN`, `GND` (both headers), `RESET` (both headers, tied
to `NRST`), and `AREF`. **SWDIO/SWCLK (PA13/PA14) aren't on this header at
all** — they're only on the separate ST-Link debug section.

**`D0`/`D1` are silkscreened as `D0/RX` and `D1/TX`**, not bare `D0`/`D1` —
they're the primary USART1 pins (PA10=RX, PA9=TX), common enough that ST
prints both labels together. Look for the compound label, right next to
`RST`/`GND` at the top of the left header.

**Reserved/unavailable pins — do not wire anything to these, and don't
reassign them in CubeMX either.** Verified against this board's own
definition file in the installed STM32CubeMX
(`db\plugins\boardmanager\boards\B41_Nucleo_NUCLEO-L432KC_STM32L432KC_Board.ioc`)
and the MCU's pinout XML (`db\mcu\STM32L432K(B-C)Ux.xml`):
- **PA13, PA14** — ST-Link SWD (SWDIO/SWCLK). Not on the Arduino header.
- **PA15** — ST-Link VCP_RX (also JTDI). Not on the Arduino header.
- **A7 (PA2)** — ST-Link VCP_TX (USART2_TX) — the virtual COM port's
  transmit line, wired straight to the ST-Link's USB-serial bridge.
- **A0 (PA0)** — locked by this board to `RCC_CK_IN` (MCO/high-speed clock in).
- **D13 (PB3)** — the on-board green LED, **LD3**.
- **D7, D8 (PC14, PC15)** — 32.768kHz crystal (OSC32_IN/OUT).
- **PB2 does not exist** on this package at all (pin numbering jumps PB1 →
  VDD/VSS → PA8) — an earlier draft of this doc used it by mistake. It has
  no Arduino header label either.

That leaves exactly 17 free GPIOs, which is exactly what this bench rig
needs — no margin, so if you add anything later you'll need to drop
something else or move to a bigger Nucleo.

## Required board mod: cut SB16 and SB18 before wiring A4/A5/D4/D5

**This is not optional for this pin plan — do it before wiring the kill
button, servo, yellow LED, or heartbeat LED.** Confirmed from ST's own
board manual (UM1956, "Table 8. Solder bridges"), this board (Rev C, which
is what ships today) has two solder bridges **closed by default**:

- **SB16**: ties `PB6` (`D5`) to `A5` (`PA6`) for optional I2C SDA support
  on `A5`. Per the manual, when SB16 is on, *"PA6 must be configured as
  input floating"* — i.e. `D5`/`PB6` and `A5`/`PA6` are not independent
  pins, they're electrically the same node.
- **SB18**: same thing for `PA5` (`A4`) and `PB7` (`D4`), I2C SCL.

In this pin plan, `A5`/`PA6` is the **kill button** and `D5`/`PB6` is the
**yellow LED**; `A4`/`PA5` is the **servo PWM** and `D4`/`PB7` is the
**heartbeat LED**. With the bridges closed, each LED's push-pull GPIO
output fights the paired input pin's pull-up/PWM signal through the
bridge — this is exactly what caused the kill button to read permanently
low regardless of wiring, reproduced identically on two separate boards,
until this was traced back to the schematic. It is a documented board
design, not a defect.

**Fix**: on this board, `SB16`/`SB18` are each implemented as a tiny SMD 0Ω
resistor (small black rectangular package, not a solder blob or scoreable
trace), located near the `CN4` connector/`PB6`/`PB7` area — look closely on
both sides of the board, they're small. Desolder and remove each one: a
fine-tip iron (a standard chisel tip is too big), heat one end until the
joint is liquid, gently nudge the resistor off that pad, then repeat on
the other end if needed; flux helps a lot if you have it. Confirm removal
with a continuity/resistance check across the two now-separated pads
(should read open). Removing them is exactly what ST's manual describes as
the "off" state, and restores `A4`/`A5`/`D4`/`D5` to fully independent
operation — precisely what this design already assumes everywhere else.
Keep the removed resistors somewhere safe — re-soldering one back restores
the I2C-sharing behavior if some future project ever wants it.

**Remove the factory jumper cap between `GND` and `D2` before wiring
anything.** The board ships with a spare 2-pin jumper cap parked across
`GND`/`D2` (`PA12`) on CN3 — it's not a functional connection, just a safe
place for ST to park a spare clip (confirmed on ST's community forum; some
of ST's own low-power example projects use that same pin deliberately as a
wake-up input, but that's opt-in for that example, not inherent to the
board). Since `D2`/`PA12` is **7-segment segment f** in this pin plan,
leaving the jumper in place would permanently short that GPIO to ground.
Pull it off and set it aside.

## Power rails: 3V3 vs 5V vs VIN

Use **3V3** for the breadboard's main power rail (the pot) — it's the
board's regulated 3.3V *output*, meant exactly for powering external
components. (The 7-segment display's common pin goes to GND instead — it's
confirmed common-cathode, see below.)

**Don't use VIN for this.** VIN is a power *input* — where you'd connect an
external battery/adapter if powering the board from something other than
USB. Since this rig is powered over USB/ST-Link, VIN is just unconnected;
wiring a rail to it gets you nothing.

This isn't just about convenience: the pot feeds directly into the STM32's
ADC (`A1`/`PA1`, `ADC1_IN6`), and the ADC input range is tied to the chip's
own supply (VDDA ≈ 3.3V). If that rail were somehow at 5V instead, the
wiper could swing above 3.3V and overdrive the ADC pin beyond spec — a real
risk to the MCU, not just a bad reading. 3V3 is the only rail that's safe
to feed into that pin.

The **servo is the one exception** — it gets its own separate connection
from the **5V** pin straight to its power lead (see the SG90 section
below), not the same 3V3 rail as the pot. Don't cross the two: servo power
doesn't go on the 3V3 rail, and the pot/display-common rail doesn't go to
5V.

## Pin table

| Function | Arduino label | STM32 pin | Direction | Notes |
|---|---|---|---|---|
| Throttle pot wiper | A1 | PA1 (ADC1_IN6) | analog in | |
| Start button | A2 | PA3 | in, internal pull-up | |
| Cruise button | A3 | PA4 | in, internal pull-up | |
| Servo PWM | A4 | PA5 (TIM2_CH1) | out | 50 Hz PWM |
| Kill button | A5 | PA6 | in, internal pull-up | |
| 7-seg segment a | A6 | PA7 | out | |
| 7-seg segment b | D9 | PA8 | out | |
| 7-seg segment c | D1/TX | PA9 | out | |
| 7-seg segment d | D0/RX | PA10 | out | |
| 7-seg segment e | D10 | PA11 | out | |
| 7-seg segment f | D2 | PA12 | out | |
| 7-seg segment g | D3 | PB0 | out | |
| Piezo buzzer | D6 | PB1 | out | |
| Green LED ("engine running" proxy) | D12 | PB4 | out | |
| Red LED (killed) | D11 | PB5 | out | |
| Yellow LED (cranking) | D5 | PB6 | out | |
| Heartbeat LED | D4 | PB7 | out | |

## Buttons (start / cruise / kill)

Each button: one leg to the GPIO pin, other leg to GND. Enable the STM32's
**internal pull-up** on each pin in CubeMX (see `cubemx-config.md`) — no
external pull resistor needed. Pressed = pin reads LOW (active-low); this
matches how `handle_firmware.c`'s cruise/start/aux inputs are described
(closed = active) even though on the real handle these come from switches on
different nets — here they're just breadboard pushbuttons standing in for
that same logical signal. The firmware debounces all three in software (see
`bench-behavior.md`) — bounce doesn't need to be fixed in hardware.

## Potentiometer (B103, 10kΩ linear)

3-terminal wiring: outer terminals to 3V3 and GND (either way — it just
flips which end of rotation reads 0 vs 255), wiper (center terminal) to
**A1 (PA1)**. This gives a clean 0–3.3V sweep into ADC1_IN6.

## SG90 servo

3 wires, standard SG90 color code:
- **Brown → GND**
- **Red → 5V**
- **Orange → A4 (PA5)** (signal)

The SG90 draws up to ~250mA stalled — **don't power it from the Nucleo's 3V3 pin** (it's not a
servo-grade rail and it's only 3.3V, out of spec for the servo anyway). Use
the Nucleo-32's `5V` header pin (sourced from USB when connected via
ST-Link) for this single low-duty SG90 on the bench. If you see the board
reset or brown out when the servo moves under load, that 5V rail is
marginal — switch to a separate 5V bench supply/USB power brick for the
servo, with grounds still tied together.

## Piezo buzzer

Two-lead piezo: one lead to **D6 (PB1)**, other to GND. If it's a passive piezo
element (no built-in oscillator), a plain GPIO high/low won't produce a
tone — the current MVP behavior is on/off only (a click/pop, not a tone),
which is enough for the state-transition beeps this rig uses. Swap to a
`TIM` PWM pin later if you want an audible tone instead of a click.

## 5611AH single-digit 7-segment display

**Confirmed common-cathode** per the manufacturer datasheet (XLITX
5611AH, 0.56", ultra-bright red) — no polarity test needed. Wire the
common pin to **GND**. `DISPLAY_COMMON_ANODE` in `firmware/Inc/bench_app.h`
is already set to `0` (cathode) to match.

Datasheet electro-optical specs relevant to the resistor choice:
- Forward voltage (VF): 1.8V typical
- Max continuous forward current per segment: 30mA (absolute max — stay
  well under this)

At the STM32's 3.3V GPIO drive: `R = (3.3V − 1.8V) / I = 1.5V / I`. A
**150–220Ω** resistor gives ~7–10mA per segment — comfortably under both
the LED's 30mA max and a typical GPIO's ~20mA safe drive limit, while
still bright enough for bench use. Put one resistor per segment pin (a–g)
in series, to **A6, D9, D1/TX, D0/RX, D10, D2, D3** (per the pin table
above). The decimal point (dp) segment is intentionally left
unconnected — not needed for a 0–9 readout.

## LEDs (green / red / yellow / heartbeat)

Standard LED wiring: GPIO pin → resistor (~220–330Ω, depends on the LED's
forward voltage/current — err toward 330Ω if unsure) → LED anode → LED
cathode → GND.

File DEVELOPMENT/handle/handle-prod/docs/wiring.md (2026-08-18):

# Wiring — handle-prod (production handle/transmitter, not a bring-up board)

**Visual reference:** `wiring-diagram.html` (open in a browser) draws every
pin/component below as a schematic; `trigger-filter-wiring.html` is a
focused close-up of just the trigger's RC anti-alias filter sub-circuit.
Both are generated from this doc and should be kept in sync with it, not
treated as an independent source of truth.

Board: **STM32L432KC Nucleo-32** — a fresh, unmodified board (SB16/SB18
solder bridges NOT removed), same reasoning as receiver-prod: the pin plan
below never uses both sides of either bridge pair (`PA5`↔`PB7`, `PA6`↔`PB6`)
at once, so no desoldering is needed.

Same Arduino-label convention as the other wiring docs: every pin below is
given as **Arduino label (STM32 name)**.

## Pin table

| Function | Arduino label | STM32 pin | Direction | Resistor | Notes |
|---|---|---|---|---|---|
| AUX1 indicator LED | A0 | PA0 (`AUX1_LED`) | out | 220–330Ω | mirrors this board's own AUX1 latch state |
| Radio CE | A1 | PA1 (`NRF_CE`) | out | - | |
| Radio CSN | A2 | PA3 (`NRF_CSN`) | out | - | |
| Kill switch | A3 | PA4 (`KILL_SW`) | in, pull-up | - (internal) | active-high (open/broken = kill) - currently a NO jumper stand-in, see "Kill switch" below |
| Trigger position | A4 | PA5 (`TRIGGER_ADC`, `ADC1_IN10`) | analog in | 100kΩ pull-down (wiper node → GND) | see "Trigger" below |
| AUX2 switch (smoke) | A5 | PA6 (`AUX2_SW`) | in, pull-down | - (internal) | momentary, active-high (closed = on) - other leg to **3V3**, not GND |
| Cruise button | A6 | PA7 (`CRUISE_BTN`) | in, pull-down | - (internal) | active-high (closed = pressed) - other leg to **3V3**, not GND |
| Start button | D3 | PB0 (`START_BTN`) | in, pull-up | - (internal) | active-low (pressed = LOW) |
| AUX1 switch (strobe) | D6 | PB1 (`AUX1_SW`) | in, pull-down | - (internal) | momentary button, but **latched in firmware** (toggle on/off) - other leg to **3V3**, not GND |
| Status LED red | D9 | PA8 (`LED_RED`) | out | 220Ω | |
| Status LED green | D1/TX | PA9 (`LED_GREEN`) | out | 220Ω | |
| Cruise indicator LED | D0/RX | PA10 (`CRUISE_LED`, relabeled from `LED_BLUE` 2026-08-09) | out | 220–330Ω | Same pin, now drives a standalone single-color blue LED instead of the tri-color package's blue lead — see "Status LED" below. |
| AUX2 indicator LED | D10 | PA11 (`AUX2_LED`) | out | 220–330Ω | mirrors this board's own live AUX2 level |
| Radio SCK | D13 | PB3 (`SPI1_SCK`) | out | - | onboard LD3 flickers with SPI clock - harmless |
| Radio MISO | D12 | PB4 (`SPI1_MISO`) | in | - | |
| Radio MOSI | D11 | PB5 (`SPI1_MOSI`) | out | - | |

Cruise, AUX1, and AUX2 use the opposite pull convention from kill/start
(pull-down vs pull-up), so their "other leg" goes to 3V3 instead of GND -
easy to mix up wiring several buttons in a row (confirmed the hard way on
the bench: wiring cruise/AUX1 to GND like kill/start meant those pins
could never read HIGH, so neither button did anything until corrected).

16 of 17 usable pins committed, 1 spare (`PA2`/`VCP_TX` - wired to the
ST-Link VCP by default; leave it alone unless USB serial debug is ever
needed).

## Radio (nRF24L01+PA+LNA)

Same module/wiring/decoupling as every other board in this project (10-100µF
electrolytic + 0.1µF ceramic at the module's V+/GND). See
`DEVELOPMENT/radio/README.md` for the bring-up history.

## Trigger

**This is the actual throttle trigger position sensor** - not a placeholder,
unlike the bench rig's simulated pot. `read_throttle_position()` in
`src/handle/handle_firmware.c` calls out the fail-safe wiring requirement
explicitly:

- Pot's low (idle) end → **GND**
- Pot's high end → **3V3**
- Wiper → **A4 (PA5)**

Orient the pot so the wiper idles toward the GND end at trigger release -
**a broken/disconnected wiper wire must read ~0 (idle), never a spurious
high throttle.** A 100kΩ pull-down is wired directly on the ADC line as
extra insurance against a wiper-wire-only disconnect (in addition to, not
instead of, the pot's own resistive path) - same fail-safe-state philosophy
as the kill switch's polarity. High enough not to meaningfully load the
pot's live signal, low enough to firmly define ~0V if the wiper wire opens.
**Must be wired in parallel** (a separate leg from the wiper node straight
to GND) - **not** spliced in series into the wiper wire itself, which
would defeat the fail-safe purpose entirely (the pin would still float if
the wire broke anywhere in that chain) and would also starve the ADC's
very short sampling time (`ADC_SAMPLETIME_2CYCLES_5`, tuned for a
low-impedance source) of enough time to charge the sample capacitor.

**Not yet measured**: real ADC min/max at full release / full pull.
`read_throttle_position()`'s 0-4095 → 0-255 mapping currently assumes the
full rail-to-rail range; retune once the pot is wired and its actual travel
is measured on the bench.

**Anti-alias RC filter (2026-08-14, wired; corrected + upgraded to ceramic
2026-08-17):** hand/engine vibration above the 80Hz sample rate's Nyquist
aliases and can't be fixed after the fact - see `docs/OPEN-ITEMS.md`
"Trigger-ADC anti-alias + oversampling" for the full reasoning. **R1 = 1kΩ
in series between the wiper and the node; C1 = 2.2µF ceramic (50V,
EIA-coded `225`) from that node to GND, cutoff ≈72Hz** (deliberately
chosen below the original ~100Hz estimate for more margin under the
Moster 185's ~120-130Hz fundamental vibration frequency at max RPM). C1 is
a ceramic capacitor - **not polarized, no lead orientation to worry
about** (this is also why it replaced the original electrolytic - see
below). Sits at the exact same node as the 100kΩ pull-down above, in
parallel with it - the pull-down is untouched.

**Wiring bug found + fixed (2026-08-17).** From the original 2026-08-14
install until this date, R1 was physically wired on the *wrong* side of
the filter node - i.e. `wiper → [node: C1, 100kΩ pull-down] → R1 → pin`,
instead of the intended `wiper → R1 → [node: C1, 100kΩ pull-down, pin]`.
Two consequences:
- **The calculated 72Hz cutoff was never actually in effect.** With C1 on
  the source side of R1, the filter's real series resistance was the
  pot's own internal wiper resistance (which varies with trigger
  position and is generally well under 1kΩ), not the fixed, known 1kΩ -
  so the real cutoff was higher than 72Hz and drifted with trigger
  position instead of being fixed. Any bench data collected in this
  window (e.g. the 2026-08-15 held-position jitter check) didn't actually
  validate the filter's frequency response - only a static-position
  jitter check, which this wiring bug wouldn't have shown up in either
  way.
- **The wiper-wire fail-safe was never actually compromised** - the
  pull-down was still directly on the node the wiper wire lands on, so a
  broken wiper wire still correctly pulled the pin to 0V through R1 (no
  current flows at DC steady-state, so no drop across R1). But an **R1
  open-failure would have left the pin fully floating**, stranded past
  the pull-down with no fail-safe path - a real gap in a vibration-heavy
  environment where lead/solder fatigue is plausible. The corrected
  topology (pull-down at the same node as the pin, independent of R1)
  protects against both failure modes, not just a broken wiper wire.

The original on-hand ceramics (0.1µF) were too small to reach ~72Hz
without a series R high enough to meaningfully load against the
pull-down - a proper-value ceramic kit arrived 2026-08-17 and was used for
this swap instead.

**Required matching change:** the trigger channel's ADC sampling time in
CubeMX needs lengthening from the current very short
`ADC_SAMPLETIME_2CYCLES_5` - that won't let the sample capacitor charge
through the new series resistance. The firmware oversampling half
(`TRIGGER_OVERSAMPLE_COUNT`) is already in place and doesn't need this to
work, but the two together are what actually solves aliasing.

## Kill switch

Fail-safe: **normally-closed**, pull-up already enabled in CubeMX, so open
or a broken wire reads HIGH = kill (the failure state is the safe state).
One leg to **A3 (PA4)**, other leg to **GND**. See
`docs/decisions/0003-fail-safe-kill-polarity.md`.

**Currently a bench-test stand-in only**: the switch on hand is
normally-open, which is backwards for this design (idle would read as
permanent kill, and a broken wire would fail silently instead of toward
kill). Bench-testing everything else uses a plain jumper wire bridging the
two leads closed. **Must be swapped for a genuinely normally-closed
switch/contact block before this is wired for real** - see
`docs/OPEN-ITEMS.md`.

## Start button

Momentary, pull-up, active-low (pressed = LOW) - same convention as the
receiver's local start button. One leg to **D3 (PB0)**, other leg to
**GND**. Hold-to-start timing (`START_HOLD_REQUIRED_MS`) is handled in
firmware, not here.

## Cruise button

Momentary, pull-down, active-high (closed = pressed). One leg to
**A6 (PA7)**, other leg to **3V3**.

## AUX1 switch (strobe) — latching

**Confirmed working on real hardware 2026-08-09** — press-to-latch-on,
press-again-to-off, receiver-side AUX1 output tracking correctly.

Physically a plain momentary pushbutton, pull-down, active-high (closed =
on) - same convention and same physical switch type as cruise. One leg to
**D6 (PB1)**, other leg to **3V3**. The latching behavior (press once to
turn on, press again to turn off) is entirely in firmware
(`handle_firmware.c`'s `build_packet()`, toggling on a rising edge - same
shape as `apply_cruise()`'s toggle) - the switch itself is not a
maintained-position part.

## AUX2 switch (smoke) — momentary

**Confirmed working on real hardware 2026-08-09** — on only while held,
receiver-side AUX2 output tracking correctly.

Physically identical wiring style to AUX1/cruise (momentary pushbutton,
pull-down, active-high, other leg to 3V3), but **no latching in
firmware** - it's a pure live level, on only while held. One leg to
**A5 (PA6)**, other leg to **3V3**.

## AUX1 / AUX2 indicator LEDs

**Confirmed working on real hardware 2026-08-09.**

Local-only indicators - each shows what THIS board is currently
commanding, not confirmation the receiver received/applied it (no
telemetry downlink exists). Standard single LEDs, same style as
receiver-prod's original AUX test LEDs:

- AUX1: **A0 (PA0)** → 220–330Ω resistor → LED anode → LED cathode → GND.
  Lit while AUX1 is latched on.
- AUX2: **D10 (PA11)** → 220–330Ω resistor → LED anode → LED cathode →
  GND. Lit while the AUX2 button is actively held.

## Status LED (red + green — bi-color, not the original tri-color package)

**2026-08-09: the tri-color package's blue lead was disconnected** - status
now only needs red+green (see "Behavior" below), and blue was freed up for
the separate cruise indicator instead (see "Cruise indicator LED" below).

**Confirm common-cathode and the physical pin order before wiring** - do
not assume this is the identical part/pinout as receiver-prod's LED even if
it's nominally "the same type"; verify with a multimeter/continuity check
the same way we did for that one (common pin → GND, each color pin through
a resistor → 3.3V, confirm which physical lead lights which color).

- Common → **GND**
- Red → 220Ω resistor → **D9 (PA8)**
- Green → 220Ω resistor → **D1/TX (PA9)**
- Blue → **disconnected** - was → 220Ω resistor → `PA10`, now freed for
  the cruise LED below.

**Behavior** (see `DEVELOPMENT/handle/handle-prod/Inc/handle_app.h` for the
authoritative writeup, priority highest first): kill latched → red,
long-long blink; holding start → yellow (red+green together), solid;
running proxy (latched on release of a confirmed start-hold, never a
telemetry-confirmed fact) → green, solid; default/armed-never-started →
red, lub-dub heartbeat. This is what shows right after boot or a re-arm -
not green, unlike before this change.

## Cruise indicator LED

**New 2026-08-09**, standalone single-color blue LED (not part of the
tri-color package above) - same wiring style as the AUX1/AUX2 indicator
LEDs: **D0/RX (PA10)** → 220–330Ω resistor → LED anode → LED cathode →
GND. Solid while `g_cruise_engaged` is set, off otherwise - no logic
change from before, just relocated off the status LED. Independent of the
status LED's state model entirely.

## Known gaps — deliberately left unconnected

- **Handle battery power**: onboard battery *sensing* was dropped entirely
  (2026-08-08 - standalone battery meters on the pack instead; 2026-08-17 -
  no battery sensing anywhere in this project now, see
  `docs/OPEN-ITEMS.md` "Battery readout wiring"), but the board still needs
  an actual power source for field use, separate from bench power over USB.
  Pack chemistry/voltage is still open - see `docs/OPEN-ITEMS.md` "Servo
  power architecture (decision)" (handle's own supply isn't blocked on
  firmware, just on picking a pack).

## Power rails: 3V3 vs 5V vs VIN

Same guidance as the other boards: **3V3** for the LED/logic/pot rail. No
5V need here (no servo on this board). **VIN** unconnected while
bench-powered over USB.

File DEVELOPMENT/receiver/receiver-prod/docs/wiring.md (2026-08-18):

# Wiring — receiver-prod (production receiver, not the bench rig)

**Visual reference:** `wiring-diagram.html` (open in a browser) draws every
pin/component below as a schematic, including the two known-gap items (kill
relay, starter relay) visually distinguished from what's actually wired.
Generated from this doc — keep in sync with it, not an independent source
of truth.

Board: **STM32L432KC Nucleo-32** — the second `spi-bringup` board ("board B"),
**unmodified** (SB16/SB18 solder bridges NOT removed). This is deliberate:
the pin plan below avoids using both sides of either bridge pair
(`PA5`↔`PB7`, `PA6`↔`PB6`) simultaneously, so no desoldering is needed — see
"Why no solder-bridge rework" below.

This is a **different board and pin plan from the bench rig**
(`DEVELOPMENT/receiver/firmware/`, see `DEVELOPMENT/receiver/docs/wiring.md`)
— it drives real hardware (servo, radio, relays) instead of simulating
wireless input from local breadboard buttons/a pot. Same Arduino-label
convention as that doc: every pin below is given as **Arduino label (STM32
name)**.

## Pin table

| Function | Arduino label | STM32 pin | Direction | Notes |
|---|---|---|---|---|
| Radio CE | A1 | PA1 (`NRF_CE`) | out | |
| Radio CSN | A2 | PA3 (`NRF_CSN`) | out | |
| Kill relay | A3 | PA4 (`KILL_RELAY`) | out | **Not yet wired** — see "Known gaps" |
| Servo PWM | A4 | PA5 (`TIM2_CH1`) | out | 50Hz, see "Servo" below |
| Battery sense | A5 | PA6 (`BATT_SENSE`, `ADC1_IN11`) | analog in | **Permanently unused** — see "Battery sense" below, not a gap to fill |
| Status LED red | A6 | PA7 (`LED_RED`) | out | |
| Local start button | D3 | PB0 (`LOCAL_START_BTN`) | in, internal pull-up | |
| Starter relay | D6 | PB1 (`STARTER_RELAY`) | out | **Not yet wired** — see "Known gaps" |
| Status LED green | D9 | PA8 (`LED_GREEN`) | out | |
| AUX1 (lights, placeholder LED for now) | D1/TX | PA9 (`AUX1_OUT`) | out | |
| AUX2 (smoke, placeholder LED for now) | D0/RX | PA10 (`AUX2_OUT`) | out | Removed 2026-08-08 to save a pin on the handle, restored 2026-08-09 once pins freed up elsewhere on that board — never actually un-assigned here, so no CubeMX changes were needed. |
| Cruise indicator LED | D10 | PA11 (`CRUISE_LED`, relabeled from `LED_BLUE` 2026-08-09) | out | Same pin, now drives a standalone single-color blue LED instead of the tri-color package's blue lead — see "Status LED" below. |
| Radio SCK | D13 | PB3 (`SPI1_SCK`) | out | onboard LD3 flickers with SPI clock — harmless |
| Radio MISO | D12 | PB4 (`SPI1_MISO`) | in | |
| Radio MOSI | D11 | PB5 (`SPI1_MOSI`) | out | |

15 of 17 usable pins committed, 2 spare.

## Why no solder-bridge rework

`PA5` (servo) and `PA7`/`PA8`/`PA11` (LEDs) are all actively used, but none of
them share a bridge pair with anything else actively used: `PA5`'s pair
partner is `PB7`, and `PA6`'s pair partner is `PB6` — **neither `PB7` nor
`PB6` is used anywhere in this pin plan**. A bridge only causes a conflict
when *both* paired pins are actively driven; leaving one side genuinely
unused sidesteps the whole issue without touching the board. This was a
deliberate constraint when picking pins (see the project conversation this
doc was extracted from, and `DEVELOPMENT/radio/README.md`'s solder-bridge
note for the original discovery of this board quirk).

## Radio (nRF24L01+PA+LNA)

**Reused unchanged from `DEVELOPMENT/radio/spi-bringup/`** — same module,
same wiring, same decoupling caps (10–100µF electrolytic + 0.1µF ceramic at
the module's V+/GND). Don't rewire anything here; this is exactly the
bring-up setup that already proved a working two-board link. See
`DEVELOPMENT/radio/README.md` for the full bring-up history.

## Servo

**Currently an SG90 micro servo — bench-test placeholder, not the final
actuator.** See `docs/OPEN-ITEMS.md` "Servo selection": a fish scale is on
hand for measuring the real throttle cable pull force, which will pick a
proper metal-gear servo later. `prod_app.c`'s `SERVO_PULSE_MIN_US`/
`SERVO_PULSE_MAX_US` (1000–2000µs) may need retuning for that servo's
actual travel, but the 50Hz frame rate (`TIM2` Prescaler=31, Period=19999)
should hold for any standard-protocol servo.

3 wires, standard SG90 color code (same as the bench rig's):
- **Brown → GND**
- **Red → 5V** (the Nucleo's `5V` header pin, sourced from USB when
  connected via ST-Link) — **not** the `3V3` pin, same reasoning as the
  bench rig: the servo draws more current than that rail is sized for, and
  it needs 5V anyway. If the board resets/browns out when the servo moves,
  switch to a separate 5V supply, grounds still tied together.
- **Orange → A4 (PA5)** (signal)

## Status LED (red + green — bi-color, not the original tri-color package)

**2026-08-09: the tri-color package's blue lead was disconnected** — status
now only needs red+green (see "Behavior" below), and blue was freed up for
a separate, dedicated cruise indicator instead (see "Cruise indicator LED"
below). The red/green wiring/pins are unchanged from before.

**Confirmed common cathode** — verified directly: common (longest) pin to
GND, red pin through a 220Ω resistor to 3.3V, lit red. Matches what
`prod_app.c` already assumes (`GPIO_PIN_SET` = lit).

**Physical pin order on this specific package: B-G-C-R** (Blue, Green,
Common, Red, reading across the 4 leads in order — equivalently R-C-G-B
from the other end). The common (C) pin is the longest lead; it's the
*second* pin from the blue end, not an outer pin, so it's easy to
miscount by one under this specific part — check the long lead, not just
position, before wiring. (Still relevant even with blue disconnected,
since the package's physical layout hasn't changed — only its blue lead
is now unwired.)

- Common (longest lead, 2nd from the blue end) → **GND**
- Red (outer pin, opposite end from blue) → 220Ω resistor → **A6 (PA7)**
- Green (between blue and common) → 220Ω resistor → **D9 (PA8)**
- Blue (outer pin, opposite end from red) → **disconnected** — was
  → 220Ω resistor → `PA11`, now freed for the cruise LED below.

220Ω was chosen because it's already confirmed working on the red channel;
green typically has a higher forward voltage than red, so it may read
visibly dimmer at the same resistor value — fine for a first pass, worth
individually tuning later if the brightness mismatch bothers you.

**Behavior** (see `prod_app.h` for the authoritative writeup, priority
highest first): killed → red, long-long blink; cranking (`STATE_STARTING`)
→ yellow (red+green together), solid; running proxy (latched on a
voluntary release from cranking, never a forced stop) → green, solid;
default/armed-never-started → red, lub-dub heartbeat (~2.5s cycle, fixed -
no battery-low speedup, see "Battery sense" below for why). This is what
shows right after boot or a re-arm — not green, unlike before this change.

## Cruise indicator LED

**New 2026-08-09**, standalone single-color blue LED (not part of the
tri-color package above) — same wiring style as the AUX1/AUX2 indicator
LEDs below: **D10 (PA11)** → 220–330Ω resistor → LED anode → LED cathode
→ GND. Solid while `g_cruise_active` (receiver_firmware.c) is set, off
otherwise — see `prod_app.h` for the full writeup. Independent of the
status LED's state model entirely.

## Local start button

Ground-crew start override, independent of the wireless link (see
`start_tick()` in `src/receiver/receiver_firmware.c`). One leg to **D3
(PB0)**, other leg to **GND** — internal pull-up already enabled in CubeMX,
active-low (pressed = pin reads LOW), same convention as every other button
in this project. No hold-to-start timer, just debounced
(`INPUT_DEBOUNCE_MS`) — see the project's discussion for why (a deliberately
placed physical button on an installed unit, not something loose that could
get bumped).

## AUX1 / AUX2 (accessory outputs)

**Confirmed working on real hardware 2026-08-09** — both outputs
correctly track the handle's commanded state (AUX1 latched, AUX2
momentary) over the radio link.

Eventually these will drive relays (AUX1 a strobe light circuit, AUX2 a
smoke circuit). **For now, each is wired as an individual indicator LED**
just to confirm the circuit is functioning — standard LED wiring (a plain
single LED, not part of the tri-color package):

- AUX1: **D1/TX (PA9)** → resistor (~220–330Ω) → LED anode → LED
  cathode → GND.
- AUX2: **D0/RX (PA10)** → resistor (~220–330Ω) → LED anode → LED
  cathode → GND.

The receiver treats both as plain level flags and doesn't know or care
that the handle latches AUX1 (toggle on/off) while leaving AUX2 purely
momentary — see `DEVELOPMENT/handle/handle-prod/docs/wiring.md` for that
distinction.

(AUX2 was removed 2026-08-08 to save a pin budget on the handle, then
restored 2026-08-09 once pins freed up elsewhere on that board.)

## Known gaps — deliberately left unconnected

These two pins are configured in CubeMX and referenced in firmware, but
**not yet wired to anything**, because each is blocked on information this
project doesn't have yet. Leaving them floating is electrically harmless —
they just won't do anything meaningful until wired.

- **Kill relay (A3/PA4)** and **starter relay (D6/PB1)**: a GPIO pin can't
  directly drive a relay coil (needs far more current than the ~20mA a GPIO
  can source) — each needs a transistor/MOSFET driver stage or an
  opto-isolated relay module in between. Per `docs/OPEN-ITEMS.md` ("Kill
  driver", "Starter driver"), the actual Vittorazi Moster 185 kill-wire
  voltage/behavior and starter solenoid coil voltage/current haven't been
  measured yet — needed to spec the driver circuit before wiring this for
  real.

## Battery sense (A5/PA6) — permanently unused, not a gap

**Decision (2026-08-17): no battery sensing on this board, ever.** The
`BATT_SENSE`/`ADC1_IN11` channel is still configured in CubeMX (freeing the
pin would need a CubeMX regenerate, not done as part of this decision), but
`read_battery_mv()`, `g_batt_low`, and all firmware that consumed them are
deleted, not just left unwired - this isn't a "measure the pack later" gap
like the two above. Leave this pin floating; **never connect a battery pack
to it** regardless of voltage. Standalone battery meters wired straight to
the packs are the only battery indication either board has (see
`docs/OPEN-ITEMS.md` "Battery readout wiring").

## Power rails: 3V3 vs 5V vs VIN

Same guidance as the bench rig (`DEVELOPMENT/receiver/docs/wiring.md`): use
**3V3** for the LED/logic-level rail, **5V** for the servo specifically
(sourced from USB via ST-Link), and don't use **VIN** at all — it's an
input for external power, unconnected while bench-powered over USB.

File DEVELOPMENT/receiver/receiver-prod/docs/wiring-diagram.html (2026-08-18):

receiver-prod · engine unit

# Receiver-prod wiring

STM32L432KC Nucleo-32 (the second spi-bringup board, unmodified) driving the engine-mounted throttle receiver: radio, servo, status/cruise/AUX indicators, and a local start button. 15 of 17 usable pins are committed — 12 are live today, 3 are configured but not yet wired pending open hardware questions. This diagram draws the actual state of the bench unit, gaps included, not the finished design.

wired & live planned — not yet wired MCU pin, connected MCU pin, floating (no load yet)

## Pin map

STM32L432KC · 15 of 17 GPIO used · 4 function clusters + 3 known gaps

Four live clusters — radio SPI (top), status / cruise / AUX LEDs (left), servo + local start button (bottom) — are wired and working. The three pins on the right — kill relay, starter relay, battery sense — are configured in CubeMX but sit unconnected: the first two are genuinely pending (blocked on driver-circuit info), while battery sense is permanently unused by decision, not a gap to fill. Each is detailed further down with why. Detailed per-cluster wiring follows below.

## Radio — nRF24L01+PA+LNA

wiredCE · CSN · SCK · MISO · MOSI

Reused unchanged from DEVELOPMENT/radio/spi-bringup/ — same module, same wiring, same decoupling. Don't rewire this; it's the exact bring-up setup that already proved a working two-board link. SCK doubles onto onboard LD3 (harmless flicker). Arrowheads show data direction — MISO is the one line running back into the MCU.

## Status LED — bi-color (red + green)

wiredcommon cathode · tri-color package, blue lead now unused

Confirmed common cathode on this exact package: common (longest lead) to GND, red through 220Ω lit red when briefly tied to 3.3V — that was a one-time bench check, not the running circuit. In operation PA7 and PA8 each drive their color through the same 220Ω resistors; green typically reads dimmer than red at this value (higher forward voltage) — fine for now, worth tuning later. The blue lead is physically disconnected, freed for the standalone cruise LED below.

## Cruise & AUX indicator LEDs

wiredthree identical single-LED circuits, placeholder indicators

Same topology three times: pin → 220–330Ω → LED → GND. All three are placeholder indicator LEDs standing in for future relay-driven loads (AUX1 → strobe light, AUX2 → smoke). Confirmed working on real hardware 2026-08-09, correctly tracking the handle's commanded state over the radio link. AUX2 was briefly removed 2026-08-08 to save a pin on the handle board and restored 2026-08-09 — never actually unassigned here, so no CubeMX changes were needed on this side. The cruise LED is new: relabeled from the old tri-color package's blue lead onto its own standalone LED on PA11.

## Servo — throttle actuator

wiredSG90 placeholder · TIM2_CH1 @ 50Hz

Standard SG90 3-wire color code. Red to 5V, not 3V3 — the servo draws more than that rail is sized for. If the board resets when the servo moves under load, switch to a separate 5V supply with grounds still tied together. SERVO_PULSE_MIN_US/SERVO_PULSE_MAX_US (1000–2000µs) may need retuning once a proper metal-gear servo replaces this placeholder — the 50Hz frame rate (TIM2 prescaler 31, period 19999) holds for any standard-protocol servo.

## Local start button

wiredground-crew override, independent of the radio link

Internal pull-up is enabled in CubeMX — there is nothing to physically wire for it. One leg to PB0, the other straight to GND, active-low (pressed = LOW), debounced (INPUT_DEBOUNCE_MS), no hold-to-start timer — a deliberately placed physical button on an installed unit, not something loose that could get bumped. This works even with the wireless link fully down: start_tick() ORs this signal with the latest wireless start request before gating a crank.

## Known gaps — two pending, one permanently unused

not wiredkill relay · starter relay unused by designbattery sense

Kill and starter relay are both configured in CubeMX and referenced in firmware, but floating on the physical board today — electrically harmless, they just do nothing until wired. Both are blocked on the same problem: a GPIO can't drive a relay coil directly (needs a transistor/MOSFET or opto driver stage), and the Moster 185's actual kill-wire and starter-solenoid voltage/current haven't been measured yet to spec that stage. Battery sense is a different kind of gap: it's not pending anything - a 2026-08-17 decision removed all battery sensing from this project, and read_battery_mv() no longer exists. The pin still carries a real electrical hazard though, since it remains a genuine ADC input on the silicon: never connect a pack above ~3.3V to it, regardless of what firmware does or doesn't read from it.

## Why no solder-bridge rework

SB16 / SB18 · board stays factory-unmodified

This Nucleo-32 keeps its SB16 (PA5↔PB7) and SB18 (PA6↔PB6) solder bridges intact — a bridge only causes a conflict when both paired pins are actively driven at once. PA5 (servo) and PA6 (battery sense) are both used here, but neither PB7 nor PB6 is used anywhere in this pin plan, so leaving them genuinely unused sidesteps the whole issue without touching the board.

This was a deliberate constraint when picking pins for this board, not an accident. The two spare pins in the pin map above (PB6, PB7) are the reason there's still headroom if a future function needs a pin — using either one is free; using both members of a pair is not.

## Power rails

3V3 · 5V · VIN

⚡ 3V3 for logic and every LED rail on this board. 5V is reserved for the servo specifically, sourced from USB through the ST-Link while bench-powered. VIN is left unconnected — it's an input for external power, not in use here.

Full pin table — receiver-prod
Function | Arduino | STM32 | Dir | Status
Radio CE | A1 | PA1 (NRF_CE) | out | wired
Radio CSN | A2 | PA3 (NRF_CSN) | out | wired
Kill relay | A3 | PA4 (KILL_RELAY) | out | not wired
Servo PWM | A4 | PA5 (TIM2_CH1) | out | wired
Battery sense | A5 | PA6 (BATT_SENSE, ADC1_IN11) | analog in | unused by design
Status LED red | A6 | PA7 (LED_RED) | out | wired
Local start button | D3 | PB0 (LOCAL_START_BTN) | in, pull-up | wired
Starter relay | D6 | PB1 (STARTER_RELAY) | out | not wired
Status LED green | D9 | PA8 (LED_GREEN) | out | wired
AUX1 (strobe placeholder) | D1/TX | PA9 (AUX1_OUT) | out | wired
AUX2 (smoke placeholder) | D0/RX | PA10 (AUX2_OUT) | out | wired
Cruise indicator LED | D10 | PA11 (CRUISE_LED) | out | wired
Radio SCK | D13 | PB3 (SPI1_SCK) | out | wired
Radio MISO | D12 | PB4 (SPI1_MISO) | in | wired
Radio MOSI | D11 | PB5 (SPI1_MOSI) | out | wired

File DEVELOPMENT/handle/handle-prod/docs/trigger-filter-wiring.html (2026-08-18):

handle-prod · trigger circuit

# Trigger anti-alias filter wiring

A 1kΩ/2.2µF RC low-pass in front of A4 (PA5), on the same node as the pre-existing 100kΩ fail-safe pull-down. Copper marks the filter addition (2026-08-14, ceramic since 2026-08-17); sage marks the original pull-down.

The pot's wiper feeds A4 (PA5) through a 1kΩ series resistor. Right at that same node — before the pin — a 2.2µF ceramic capacitor (not polarized — no lead orientation to worry about) and the existing 100kΩ fail-safe pull-down both run to ground, in parallel with each other. The pull-down is unchanged. R1 must be between the wiper and this node — not between the node and the pin — or the filter's real cutoff ends up set by the pot's own wiper resistance instead of the fixed 1kΩ (see wiring.md's 2026-08-17 wiring-bug note).

filter addition original pull-down, leave alone

Parts at that node
Part | Value | Role
R1 — series resistor | 1kΩ | Between wiper and the node (not between the node and the pin - see the wiring-bug note above). Sets the filter's source impedance. | filter
C1 — filter capacitor | 2.2µF @ 50V | Node to GND. Ceramic (EIA-coded 225), not polarized — no lead orientation to worry about. Replaced an electrolytic 2026-08-17. | filter
R2 — pull-down | 100kΩ | Node to GND. Fail-safe: pulls the pin to 0 if the wiper wire opens (and, in the corrected topology, even if R1 fails open). | original

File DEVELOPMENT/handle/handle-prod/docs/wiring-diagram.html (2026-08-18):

handle-prod · STM32L432KC Nucleo-32 · transmitter

# Handle-prod board wiring

Every committed pin on the handle transmitter: trigger position sensing with its anti-alias filter, the fail-safe kill switch, start/cruise/AUX buttons, five status/indicator LEDs, and the nRF24L01+ SPI radio link — grouped around the MCU the way the signals actually group on the bench. 16 of 17 usable pins are committed; one spare is called out where it sits.

Inputs sit on the MCU's left edge, the radio's SPI bus stays together on the right edge feeding the nRF24L01+ module, the five LED outputs run off the top edge, and the trigger's potentiometer + anti-alias filter hang below as their own bounded circuit — the same 1kΩ/2.2µF filter as the dedicated trigger diagram, still sitting at the same node as the existing 100kΩ fail-safe pull-down.

Kill is the one input wired opposite everything else (normally-closed, pull-up — open or a broken wire reads as kill) because a missed kill is dangerous while a spurious one is just a safe engine-off; every other input here is energize-to-act with a pull-down, so a broken wire can't crank the engine, engage cruise, or raise the throttle (see docs/decisions/0003-fail-safe-kill-polarity.md). The dashed copper-colored line at A3 is not that switch yet — it's today's plain bench jumper standing in for it.

Copper marks the anti-alias filter (R1, C1 - added 2026-08-14, ceramic + a wiring-bug fix 2026-08-17, see this board's wiring.md); sage marks everything else already wired and, where noted, confirmed working on real hardware 2026-08-09.

wired — existing trigger anti-alias filter stand-in / deliberately unconnected

## Pin table

handle-prod · STM32L432KC · Arduino label (STM32 name)
Function | Arduino | STM32 pin | Dir | Resistor | Notes
AUX1 indicator LED | A0 | PA0 · AUX1_LED | out | 220–330Ω | mirrors this board's own AUX1 latch state
Radio CE | A1 | PA1 · NRF_CE | out | —
Radio CSN | A2 | PA3 · NRF_CSN | out | —
Kill switch | A3 | PA4 · KILL_SW | in, pull-up | internal | active-high (open/broken = kill) — bench jumper stand-in today, see below
Trigger position | A4 | PA5 · TRIGGER_ADC / ADC1_IN10 | analog in | 100kΩ pull-down | wiper node → GND, plus 1kΩ + 2.2µF filter
AUX2 switch (smoke) | A5 | PA6 · AUX2_SW | in, pull-down | internal | momentary, active-high, other leg → 3V3
Cruise button | A6 | PA7 · CRUISE_BTN | in, pull-down | internal | active-high (closed = pressed), other leg → 3V3
Start button | D3 | PB0 · START_BTN | in, pull-up | internal | active-low (pressed = LOW), other leg → GND
AUX1 switch (strobe) | D6 | PB1 · AUX1_SW | in, pull-down | internal | momentary switch, latched in firmware, other leg → 3V3
Status LED red | D9 | PA8 · LED_RED | out | 220Ω
Status LED green | D1/TX | PA9 · LED_GREEN | out | 220Ω
Cruise indicator LED | D0/RX | PA10 · CRUISE_LED | out | 220–330Ω | relabeled from LED_BLUE 2026-08-09; now a standalone blue LED
AUX2 indicator LED | D10 | PA11 · AUX2_LED | out | 220–330Ω | mirrors this board's own live AUX2 level
Radio SCK | D13 | PB3 · SPI1_SCK | out | — | onboard LD3 flickers with SPI clock — harmless
Radio MISO | D12 | PB4 · SPI1_MISO | in | —
Radio MOSI | D11 | PB5 · SPI1_MOSI | out | —
spare | — | PA2 · VCP_TX | — | — | wired to ST-Link VCP by default — leave alone unless USB serial debug is needed

## Parts at the trigger node

same node as the dedicated trigger anti-alias filter diagram
Part | Value | Role
R1 — series resistor | 1kΩ | Between wiper and the node (not between the node and the pin - a 2026-08-17 wiring bug had this reversed). Sets the filter's source impedance; cutoff ≈ 72Hz with C1. | filter
C1 — filter capacitor | 2.2µF @ 50V | Node to GND. Ceramic (EIA-coded 225), not polarized. Replaced an electrolytic 2026-08-17. | filter
R2 — pull-down | 100kΩ | Node to GND, in parallel with C1. Fail-safe: pulls the pin to 0 if the wiper wire opens (and, in the corrected topology, even if R1 fails open). | original

### Known gaps & stand-ins

- Kill switch (A3 / PA4): the part on hand is normally-open, which is backwards for this design. Bench testing bridges the two leads with a plain jumper wire instead. Must be swapped for a genuine normally-closed switch or contact block before this is wired for real — see docs/OPEN-ITEMS.md.
- Handle battery power: onboard battery sensing was dropped entirely in favor of a standalone pack meter, but the board still needs an actual power source for field use, separate from bench power over USB. Pack chemistry/voltage is still open.
- VIN: unconnected while bench-powered over USB. This board has no 5V need (no servo here) — 3V3 is the only logic/LED/pot rail in use.
- PA2 (VCP_TX): the one uncommitted usable pin. Wired to the ST-Link virtual COM port by default — leave it alone unless USB serial debug is ever needed.
- Trigger travel: real ADC min/max at full release/full pull hasn't been measured yet; the 0–4095 → 0–255 mapping still assumes full rail-to-rail range.

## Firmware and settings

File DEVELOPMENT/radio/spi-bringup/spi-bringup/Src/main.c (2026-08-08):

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
/* Includes ------------------------------------------------------------------*/
#include <string.h>
#include <stdbool.h>
#include "main.h"
#include "spi.h"
#include "gpio.h"
#include "nrf24.h"
#include "throttle_protocol.h"
#include "crc8.h"

/* USER CODE BEGIN PD */

#define TX_PACKET_PERIOD_MS    100u  /* well under WATCHDOG_RAMP_START_MS (175ms) so the watchdog
                                        doesn't fight the sweep between every pair of packets - the
                                        real protocol runs at 80Hz (12.5ms); this bring-up test just
                                        needs to be fast enough not to look like a degraded link */
#define TX_TEST_CYCLE_PACKETS   60u  /* ~6s at TX_PACKET_PERIOD_MS/packet: how often the TX role tests START_REQ */
#define TX_TEST_START_PACKETS    9u  /* ~0.9s: how long START_REQ holds during that test window */

/* Two-board TX/RX smoke test (DEVELOPMENT/radio/README.md bring-up step 3).
 * Set to 1, build, and flash the first ("TX") board - it sends a real,
 * protocol-valid throttle_packet_t (sync/seq/CRC8 all correct, flags=0)
 * every ~300ms, with the throttle field slowly triangle-sweeping between
 * IDLE_THROTTLE_VALUE and 200 so a receiving board's servo visibly moves -
 * an easy confirmation that packets are being received and VALIDATED
 * (sync/CRC8/sequence all passing), not just that SPI/radio transactions
 * are happening. Set to 0, rebuild, and flash the second ("RX") board -
 * it listens and stores each received counter in rx_last_counter/
 * rx_packet_count (this path still expects the OLD raw-counter-in-every-
 * byte format from before this file sent real packets; only meaningful
 * against another spi-bringup board in TX role, not receiver-prod).
 * Only flash/debug one board at a time; let the other free-run on USB or
 * battery power without an attached debug session. */
#define BRINGUP_ROLE_TX 1

/* USER CODE END PD */


void SystemClock_Config(void);
/**
  * @brief  The application entry point.
  * @retval int
  */
int main(void)
{

  /* MCU Configuration--------------------------------------------------------*/

  /* Reset of all peripherals, Initializes the Flash interface and the Systick. */
  HAL_Init();

  /* Configure the system clock */
  SystemClock_Config();

  /* Initialize all configured peripherals */
  MX_GPIO_Init();
  MX_SPI1_Init();
  /* USER CODE BEGIN 2 */

  /* nRF24L01+ driver smoke test: nrf24_init() configures EN_AA, SETUP_RETR,
   * RF_CH, RF_SETUP, RX_ADDR_P0/TX_ADDR, and RX_PW_P0, then raises PWR_UP.
   * Confirmed on hardware, 2026-08-06 (see DEVELOPMENT/radio/README.md):
   *   - CONFIG:   0x0A (EN_CRC=1, PWR_UP=1, PRIM_RX=0) - our own write.
   *   - RF_SETUP: 0x24 (250kbps, PA_HIGH/-6dBm) - our own write.
   *   - RX_ADDR_P0 (5 bytes): {0xE7,0xE7,0xE7,0xE7,0xE7} - confirms
   *     multi-byte register writes/reads work too, not just single-byte. */
  nrf24_init();

  uint8_t config_val    = nrf24_read_reg(NRF24_REG_CONFIG);
  uint8_t rf_setup_val   = nrf24_read_reg(NRF24_REG_RF_SETUP);
  uint8_t rx_addr_p0[5]  = { 0 };
  nrf24_read_reg_n(NRF24_REG_RX_ADDR_P0, rx_addr_p0, 5);
  /* Never previously read back - checking these because MAX_RT (max
   * retransmits) is showing up on the TX board despite EN_AA/SETUP_RETR
   * both being written 0x00, which should make MAX_RT impossible. Expect
   * both 0x00 here; if not, the writes aren't landing as intended. */
  uint8_t en_aa_val      = nrf24_read_reg(NRF24_REG_EN_AA);
  uint8_t setup_retr_val = nrf24_read_reg(NRF24_REG_SETUP_RETR);

#if BRINGUP_ROLE_TX
  uint8_t tx_seq = 0;
  uint8_t tx_throttle = IDLE_THROTTLE_VALUE;
  int8_t  tx_sweep_dir = 1;
  uint32_t tx_packet_num = 0;
  /* Set to 1 via a debugger breakpoint/variable edit to send ONE packet
   * with CMD_FLAG_KILL, then it auto-resets to 0. Deliberately NOT part of
   * the automatic test cycle below: KILL is sticky on the receiver (needs
   * a physical re-arm/power-cycle to clear), so firing it on a timer would
   * lock board B mid-test. */
  volatile uint8_t tx_send_kill = 0;
  /* nrf24_init() already leaves the chip in TX mode (PRIM_RX=0, CE low). */
#else
  uint32_t rx_packet_count = 0;
  uint8_t rx_last_counter = 0;
  nrf24_enter_rx_mode();
#endif

  /* USER CODE END 2 */

  /* Infinite loop */
  /* USER CODE BEGIN WHILE */
  while (1)
  {
    /* USER CODE END WHILE */

    /* USER CODE BEGIN 3 */
#if BRINGUP_ROLE_TX
    /* Every TX_TEST_CYCLE_PACKETS (~6s), pause the throttle sweep and hold
     * CMD_FLAG_START_REQ + idle throttle for TX_TEST_START_PACKETS (~0.9s)
     * to satisfy start_tick()'s IDLE_THRESHOLD_FOR_START gate - a clean,
     * repeatable, non-sticky test of the wireless START path, well under
     * MAX_CRANK_MS so it always ends via voluntary release (blue LED while
     * held, green on release), never the forced-stop/cooldown path. */
    bool test_start_window = (tx_packet_num % TX_TEST_CYCLE_PACKETS) < TX_TEST_START_PACKETS;

    throttle_packet_t pkt;
    pkt.sync = PACKET_SYNC_BYTE;
    pkt.seq = tx_seq++;
    pkt.throttle = test_start_window ? IDLE_THROTTLE_VALUE : tx_throttle;
    pkt.flags = 0;
    if (tx_send_kill) {
      pkt.flags |= CMD_FLAG_KILL;
      tx_send_kill = 0; /* one-shot */
    } else if (test_start_window) {
      pkt.flags |= CMD_FLAG_START_REQ;
    }
    pkt.crc8 = crc8_compute((const uint8_t *)&pkt, PACKET_CRC_LEN);

    uint8_t raw[PACKET_SIZE];
    memcpy(raw, &pkt, PACKET_SIZE);
    nrf24_send_payload(raw, (uint8_t)PACKET_SIZE);
    uint8_t tx_fifo_status = nrf24_read_reg(NRF24_REG_FIFO_STATUS);
    (void)tx_fifo_status; /* breakpoint here if debugging; TX_EMPTY (0x10) should be set after each send */

    tx_packet_num++;

    /* Slow triangle sweep, step 1 every TX_PACKET_PERIOD_MS (~20s per
     * direction) - paused during the START test window above so throttle
     * stays at idle for that gate, then resumes from where it left off. The
     * receiving board's servo moving is a visual confirmation that packets
     * are being received AND validated, not just that radio traffic is
     * happening at all. */
    if (test_start_window) {
      /* sweep paused this packet */
    } else if (tx_sweep_dir > 0) {
      if (tx_throttle >= 200) { tx_sweep_dir = -1; } else { tx_throttle += 1; }
    } else {
      if (tx_throttle <= IDLE_THROTTLE_VALUE) { tx_sweep_dir = 1; } else { tx_throttle -= 1; }
    }

    HAL_Delay(TX_PACKET_PERIOD_MS);
#else
    if (nrf24_rx_available()) {
      uint8_t payload[NRF24_PAYLOAD_SIZE];
      nrf24_read_payload(payload, NRF24_PAYLOAD_SIZE);
      rx_last_counter = payload[0];
      rx_packet_count++; /* breakpoint here; expect rx_last_counter to climb by 1 each stop */
    }
#endif
  }
  /* USER CODE END 3 */
}

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


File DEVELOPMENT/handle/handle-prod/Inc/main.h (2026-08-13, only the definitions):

#define AUX1_LED_Pin GPIO_PIN_0
#define AUX1_LED_GPIO_Port GPIOA
#define NRF_CE_Pin GPIO_PIN_1
#define NRF_CE_GPIO_Port GPIOA
#define VCP_TX_Pin GPIO_PIN_2
#define VCP_TX_GPIO_Port GPIOA
#define NRF_CSN_Pin GPIO_PIN_3
#define NRF_CSN_GPIO_Port GPIOA
#define KILL_SW_Pin GPIO_PIN_4
#define KILL_SW_GPIO_Port GPIOA
#define TRIGGER_ADC_Pin GPIO_PIN_5
#define TRIGGER_ADC_GPIO_Port GPIOA
#define AUX2_SW_Pin GPIO_PIN_6
#define AUX2_SW_GPIO_Port GPIOA
#define CRUISE_BTN_Pin GPIO_PIN_7
#define CRUISE_BTN_GPIO_Port GPIOA
#define START_BTN_Pin GPIO_PIN_0
#define START_BTN_GPIO_Port GPIOB
#define AUX1_SW_Pin GPIO_PIN_1
#define AUX1_SW_GPIO_Port GPIOB
#define LED_RED_Pin GPIO_PIN_8
#define LED_RED_GPIO_Port GPIOA
#define LED_GREEN_Pin GPIO_PIN_9
#define LED_GREEN_GPIO_Port GPIOA
#define CRUISE_LED_Pin GPIO_PIN_10
#define CRUISE_LED_GPIO_Port GPIOA
#define AUX2_LED_Pin GPIO_PIN_11
#define AUX2_LED_GPIO_Port GPIOA
#define SWDIO_Pin GPIO_PIN_13
#define SWDIO_GPIO_Port GPIOA
#define SWCLK_Pin GPIO_PIN_14
#define SWCLK_GPIO_Port GPIOA
#define VCP_RX_Pin GPIO_PIN_15
#define VCP_RX_GPIO_Port GPIOA

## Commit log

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2026-07-05 Add battery monitor, cruise & aux support
    Introduce a portable battery monitor (battery_monitor.h) with voltage->LED mapping and non-blocking buzzer cadence. Handle firmware: add cruise-control (set/toggle/disengage), auxiliary inputs, local battery polling/LEDs/buzzer, and ensure kill precedence when building packets (CRUISE flag and AUX flags supported). Receiver firmware: add local battery monitoring, apply_aux_outputs to mirror aux flags (non-safety), call battery_tick from main loop, and apply accessories after the safety state machine. Update throttle_protocol.h with CMD_FLAG_CRUISE/CMD_FLAG_AUX1/CMD_FLAG_AUX2 and cruise constant. Hardware I/O are left as placeholders.
    [handle_firmware.c, receiver_firmware.c, throttle_protocol.h]
2026-07-05 Add kill debounce and fail-safe wiring docs
    Add 30ms debounce to kill signal via new kill_confirmed() function to reject vibration glitches while preserving fail-safe behavior (broken/open wire still triggers kill). Clarify fail-safe wiring conventions (normally-closed kill, pull-downs on throttle/inputs) in comments. Add test_logic.c for host-side validation of pure logic (CRC8, sequence rollover, cruise rules, kill debounce) without hardware. Update throttle_protocol.h with KILL_DEBOUNCE_MS constant.
    [handle_firmware.c, throttle_protocol.h]
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2026-07-05 Add RPM-based engine-caught detection (STARTING -> RUNNING)
    Receiver now confirms the engine actually started via real RPM from a
    plug-lead tach pickup, instead of the old throttle-implies-RUNNING guess.
    - engine_caught_tick (independent of packet arrival, like the watchdog):
    STARTING -> RUNNING when RPM holds >= RPM_CAUGHT_THRESHOLD for
    RPM_CAUGHT_STABLE_MS; crank times out at CRANK_TIMEOUT_MS; aborts on
    loss of signal; RPM goes stale to 0 when sparks stop.
    - Supervised, bounded cranking: kill aborts the crank, a per-tick safety
    net forces the starter off outside STATE_STARTING, and STARTER_COOLDOWN_MS
    blocks rapid re-cranking.
    - Fix (found by safety-reviewer): throttle position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
    [receiver_firmware.c, throttle_protocol.h]
2026-07-05 Switch electric start to manual crank; drop tach/RPM engine-caught
    Per ADR 0007: the pilot holds the start button to crank and releases when
    the engine catches (they hear it and have a separate RPM gauge), so there
    is no tach in the controller and no RPM-based STARTING -> RUNNING.
    Removes an EMI-coupled subsystem (plug-lead pickup + conditioning circuit)
    and two guards that were never fail-safe (RPM catch detection and the
    rpm==0 "don't crank a turning engine" gate).
    Receiver:
    - Drop STATE_RUNNING, tach/RPM state, on_tach_edge, engine_caught_tick.
    - Manual crank: rising-edge START_REQ (gated IDLE_SAFE + idle throttle +
    not recovering + cooldown) begins; release ends (no cooldown).
    - cran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
    [receiver_firmware.c, throttle_protocol.h]
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2026-07-06 Debounce the cruise button and accessory inputs
    A single cruise press could register as multiple edges through contact
    bounce, toggling cruise on-then-off. Add a generic time-based debounce
    (INPUT_DEBOUNCE_MS = 20ms) applied to the cruise button and the two
    accessory switches. Kill keeps its own dedicated fail-safe debounce; start
    is already debounced by its 600ms hold.
    - New debounce_t + debounce_update() in handle_firmware.c.
    - apply_cruise takes `now` and reads the cruise button through the debounce.
    - Aux level flags are debounced too.
    - Host tests: stable-after-threshold and bounce-rejection.
    [handle_firmware.c, throttle_protocol.h]
2026-07-06 Add throttle deadband/hysteresis on the handle
    Raw trigger jitter (hand + engine vibration) would otherwise reach the servo
    as constant small moves. Add a deadband: the mapped trigger value must move
    at least THROTTLE_DEADBAND (3/255) from the last transmitted value before it
    updates, so each servo position owns a band of trigger values and the servo
    stops hunting. Rails (0, 255) always update so full idle / full throttle stay
    exactly reachable. Complements the existing EMA filter and receiver rate-limit.
    Host tests: in-band hold (both directions), threshold pass, rail snapping.
    [handle_firmware.c, throttle_protocol.h]
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2026-07-06 Drive throttle servo to idle on kill (defense in depth)
    Previously the main loop skipped step_toward_target while STATE_KILLED and
    watchdog_tick returns early when killed, so the servo froze at its last
    position - holding the throttle plate open after a kill. If the electronic
    ignition-cut ever failed (and the mechanical kill wasn't used), the throttle
    would stay wide open.
    Now the kill branch clears g_ramping_to_idle and the main-loop guard is just
    `if (!g_ramping_to_idle)`, so the servo steps to the idle target (rate-limited)
    while killed. Target is provably idle throughout KILLED (only the kill branch
    writes it; the sticky early-return blocks any other path).
    Reviewed by safety-reviewer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
    [receiver_firmware.c]
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2026-07-06 Ramp watchdog throttle toward IDLE_THROTTLE_VALUE, not hardcoded 0
    The loss-of-signal ramp interpolated ramp_start * remaining / duration, which
    reaches 0 - correct only because IDLE_THROTTLE_VALUE happens to be 0. Interpolate
    against IDLE_THROTTLE_VALUE instead so a non-zero idle mapping still ramps to
    idle and never below it, and guard the case where current throttle is already
    at/below idle. Behavior is identical while idle == 0.
    [receiver_firmware.c]
2026-08-01 Add receiver bench-test rig (no radio yet)
    New DEVELOPMENT/receiver/ area: STM32L432KC firmware, wiring, CubeMX config,
    and a schematic for a breadboard rig that exercises the real receiver safety
    state machine via buttons/pot instead of the nRF24 radio link. bench_app.c
    pulls in receiver_firmware.c unmodified (its statics are internal-linkage,
    same translation unit) so the bench rig runs the actual kill/start/throttle/
    watchdog logic, not a reimplementation.
    The one change to receiver_firmware.c itself: millis() now calls
    HAL_GetTick() under #ifdef USE_HAL_DRIVER, since the watchdog/crank timing
    this rig tests is meaningless against a clock stuck at 0. Gated so the
    host-side compile-check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
    [bench_app.c, receiver_firmware.c]
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2026-08-01 Generate CubeMX project for the receiver bench rig, wire in bench_app
    Full STM32CubeMX-generated project for the NUCLEO-L432KC (HAL/CMSIS
    drivers, firmware.ioc, .project/.cproject), replacing the earlier bare
    CubeIDE skeleton. Board Selector -> NUCLEO-L432KC, Basic application
    structure (flat Src/Inc, not Core/Src/Core/Inc), Toolchain/IDE =
    STM32CubeIDE with "Generate under root", peripheral init as separate
    .c/.h pairs. Pin labels in main.h match the corrected bench pin plan
    (START_BTN/CRUISE_BTN/KILL_BTN, SEG_A..SEG_G, BUZZER, LED_GREEN/RED/
    YELLOW/HEARTBEAT) exactly.
    Restores bench_app.c/bench_app.h (previously cleared out to give the
    generator an empty target directory) into the generat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
    [bench_app.c, firmware.ioc, main.c]
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2026-08-03 Add KiCad schematic for the receiver bench rig
    Full electrical schematic (47 symbol instances + 3 PWR_FLAG symbols):
    potentiometer, 3 buttons, 7-segment display (7x LED+resistor, common
    cathode), 4 status LEDs, buzzer, and the servo connector, all wired
    per docs/wiring.md. MCU pins are represented as global-label wire stubs
    (e.g. A6_PA7) rather than a drawn Nucleo symbol, since no stock KiCad
    symbol exists for this dev board and hand-authoring one was the highest-
    risk part of this file -- standard KiCad practice for "this net goes to
    a board I'm not drawing".
    Hand-authored directly against the schematic format (no KiCad install in
    this environment to test against), verified against the use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
    [receiver-bench.kicad_pcb, receiver-bench.kicad_sch]
2026-08-03 Fix PWR_FLAG connections in the receiver bench schematic
    The prior PWR_FLAG placements sat a few mm from their target GND/+3V3/
    +5V symbols, joined by a short wire ending at the same point as each
    power symbol's existing wire -- a 3-way meeting point (two wire segments
    + a pin) that needs an explicit junction to register as connected, which
    the file didn't emit. ERC showed the flags as pin_not_connected and the
    original power_pin_not_driven errors persisted.
    Fixed by placing each PWR_FLAG symbol's pin at the exact same coordinate
    as its target power symbol's pin instead -- the same coincident-pin
    pattern already used throughout this file for chaining components,
    which sidesteps the junction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
    [receiver-bench.kicad_sch]
2026-08-03 Wire the real NUCLEO-L432KC symbol into the receiver bench schematic
    Replaces the implicit "MCU pins are just labels going off-page" approach
    with the actual board symbol (SnapEDA import, both CN3/CN4 header units
    placed as U1), now that a real symbol is available. Every peripheral-side
    label (e.g. D1TX_PA9) gets a matching wire+label pair at the real MCU
    pin, so the same-named-label mechanism genuinely ties the MCU into each
    net instead of just implying it. GND/+3V3/+5V on the MCU are tied in via
    the same coincident-pin trick used for the PWR_FLAG fix.
    Verified programmatically (not by inspection) that all 17 pin<->label
    pairings are correct: parsed the real pin geometry out of the file,
    c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
    [receiver-bench.kicad_sch]
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2026-08-06 Start SPI bring-up project: SPI1 on PB3/PB4/PB5, CE/CSN GPIOs, register read-back test
    New CubeMX/CubeIDE project (DEVELOPMENT/radio/spi-bringup/) for step 1 of
    the radio bring-up plan: prove SPI actually talks to an nRF24L01+PA+LNA
    module before deciding on driver approach (fork vs custom).
    SPI1 configured Full-Duplex Master on the alternate PB3(SCK)/PB4(MISO)/
    PB5(MOSI) mapping rather than the default PA5/PA6/PA7 -- those default
    pins are exactly the ones SB16/SB18 bridge on this board, and this
    project deliberately runs on a stock/unmodified Nucleo to avoid needing
    that rework. Hardware NSS disabled; CE (PA1) and CSN (PA3) are plain
    GPIO outputs, CSN toggled manually in code since a mult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
    [main.c, main.h, spi-bringup.ioc]
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2026-08-06 UNTESTED: add minimal nRF24L01+ register-level driver (nrf24.h/nrf24.c)
    Implements the small, fully-enumerated command/register surface this
    project actually needs: register read/write (single and multi-byte),
    fixed 5-byte payload configuration, no auto-ack (EN_AA=0x00, ADR 0001),
    no retries, 250kbps + PA_HIGH (-6dBm) via RF_SETUP=0x24. All command
    bytes, register addresses, and the RF_SETUP bit encoding are verified
    against the nRF24L01+ (Plus) Product Specification v1.0, now committed
    at DEVELOPMENT/assets/nRF24L01+/ -- notably NOT the older non-Plus
    nRF24L01 datasheet, which lacks 250kbps entirely and has a different
    RF_SETUP layout (caught and corrected mid-session after the user
    supplie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
    [main.c, nrf24.c]
2026-08-06 UNTESTED: fix nrf24 multi-byte reg read/write dropping to zero on hardware
    nrf24_read_reg_n/write_reg_n issued a separate blocking
    HAL_SPI_TransmitReceive call per byte under one CSN-low bracket. On the
    bring-up board this read RX_ADDR_P0 back as all-zero instead of even the
    chip's own 0xE7 reset default, indicating the per-call transactions after
    the first weren't reliably clocking. Rewritten to build one cmd+data
    buffer and send it in a single HAL call, matching the already-verified
    single-register nrf24_read_reg/write_reg pattern.
    [nrf24.c]
2026-08-06 UNTESTED: add temporary SPI status debug hooks to nrf24 multi-byte reg fns
    RX_ADDR_P0 still reads back as all-zero after switching read_reg_n/
    write_reg_n to a single HAL_SPI_TransmitReceive call, so the earlier fix
    wasn't the actual cause. Capture the HAL return status and the STATUS
    byte (rx[0], always shifted back while the command byte clocks out) from
    the last read and write multi-byte transactions in debugger-inspectable
    globals, to see whether the SPI transfer itself is erroring/timing out
    versus completing but carrying wrong data.
    [nrf24.c]
2026-08-06 Confirm nrf24 multi-byte register read/write on hardware, drop debug hooks
    CONFIG=0x0A, RF_SETUP=0x24, RX_ADDR_P0={0xE7,0xE7,0xE7,0xE7,0xE7} all
    read back correctly on the spi-bringup board after nrf24_init(), matching
    what the driver itself wrote - confirms both single- and multi-byte
    read/write paths (the earlier "all zero" reports were breakpoint timing,
    not an actual bug: the debugger was being checked before
    nrf24_read_reg_n had executed). Removes the temporary HAL-status debug
    globals now that the path is verified, and records the milestone plus
    the fork-vs-custom-driver decision in DEVELOPMENT/radio/README.md.
    [main.c, nrf24.c]
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2026-08-06 UNTESTED: clear stuck STATUS flags and flush FIFOs in nrf24_init()
    Logic analyzer showed board A's TX FIFO permanently stuck full (STATUS
    0x1F: TX_FULL + MAX_RT set) despite confirming, independently, that both
    the SPI payload write (A0 + 5 bytes) and the CE pulse (~2ms, well over
    the 10us minimum) were happening correctly. Per the datasheet, a latched
    MAX_RT blocks all further transmission until explicitly cleared - and
    nrf24_init() never did that or flushed the FIFOs. Since the nRF24
    module's own power isn't tied to the MCU's reset/reflash cycle, a fault
    latched during any earlier test this session could still be sitting
    there blocking every subsequent attempt regardless of what else chang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
    [nrf24.c]
2026-08-07 UNTESTED: read back EN_AA/SETUP_RETR to check why MAX_RT is firing on TX
    Board A is hitting a stuck MAX_RT/TX_FULL FIFO state fresh within the
    first few seconds of a run, even after nrf24_init() now clears STATUS
    and flushes both FIFOs on boot. MAX_RT should be unreachable given
    EN_AA=0x00 and SETUP_RETR=0x00 (auto-ack and auto-retransmit both
    disabled) - these two registers have never actually been read back to
    confirm the writes landed, unlike CONFIG/RF_SETUP/RX_ADDR_P0 which were
    already verified. Adds that check.
    [main.c]
2026-08-07 UNTESTED: clear STATUS and flush TX FIFO after every send, not just init
    Research into the stuck MAX_RT/TX_FULL state (despite EN_AA=0x00 and
    SETUP_RETR=0x00 confirmed via register read-back, which should make
    MAX_RT unreachable per the real nRF24L01+ datasheet) turned up a likely
    explanation: the SI24R1 clone chip commonly found on this exact PA+LNA
    module category (already flagged as a real risk in
    DEVELOPMENT/radio/README.md) has documented ACK-related behavior
    inverted from genuine nRF24L01+ parts, and clearing STATUS + flushing
    TX after every send (not just once at init) is the community-reported
    workaround for the resulting stuck-FIFO symptom on custom drivers.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
    [nrf24.c]
2026-08-07 UNTESTED: try 1Mbps instead of 250kbps to isolate RX board's silence
    TX board now confirms completed sends (STATUS.TX_DS set, no stuck FIFO)
    after the per-send clear+flush fix, and RX board's own register config
    was just verified correct and matching (CONFIG/RF_SETUP/RX_ADDR_P0/
    EN_AA/SETUP_RETR all as expected) - yet the RX board still never
    receives anything. Community reports describe 250kbps specifically as
    unreliable on various nRF24L01/clone modules even when 1Mbps works fine
    on the same hardware, so switching data rate is the next thing to rule
    in/out. This is a diagnostic-only change, not a decision on the real
    project's data rate (still open per ADR 0005) - both boards share this
    dr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
    [nrf24.c]
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2026-08-07 Leave BRINGUP_ROLE_TX at 0 (RX role) as the last-built/tested state
    No functional significance either way - this is a manual per-board
    build toggle, flipped depending on which board is being flashed next.
    Committing current state just to leave a clean working tree.
    [main.c]
2026-08-08 Promote nrf24 driver to src/common/, update firmware stubs to real API
    Parameterizes the bring-up-proven driver (nrf24_handle_t bundling an
    SPI peripheral + CE/CSN pins per instance, rather than hardcoded
    globals) so handle and receiver - which won't necessarily share a SPI
    peripheral or pin assignment - can each instantiate their own. RX_PW_P0
    now derives from throttle_protocol.h's real PACKET_SIZE instead of a
    duplicated bring-up constant.
    handle_firmware.c/receiver_firmware.c's radio stub comments are updated
    to reference the real nrf24_* calls (replacing stale TMRh20/RF24-library
    pseudocode left over from before the fork-vs-custom-driver decision),
    but stay commented rather than live: t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
    [handle_firmware.c, nrf24.c, receiver_firmware.c]
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2026-08-08 Generate receiver-prod CubeMX project: servo, radio, tri-color LED, start button
    New STM32CubeIDE project for the real (non-bench-rig) receiver board,
    distinct from DEVELOPMENT/receiver/firmware/. Pin plan:
    - Servo PWM: A4/PA5 (TIM2_CH1), 50Hz (Prescaler=31, Period=19999,
    Pulse=1500 - SG90 bench-test placeholder, see docs/OPEN-ITEMS.md)
    - Radio SPI1: PB3/PB4/PB5 (SCK/MISO/MOSI), same alternate mapping already
    proven in spi-bringup, avoiding the SB16/SB18 solder-bridge pins
    - Radio CE/CSN: A1/A2 (PA1/PA3), matching spi-bringup exactly so the
    existing nRF24 module wiring can be reused as-is
    - Tri-color status LED (R/G/B): A6/D9/D10 (PA7/PA8/PA11) - heartbeat +
    solid-red-on-kill on Red,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
    [main.c, main.h, receiver-prod.ioc]
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2026-08-08 Send real protocol-valid throttle_packet_t from spi-bringup's TX role
    Follow-up to aba8f65, which only committed the .launch file due to a
    git add error - this is the actual code/project change: main.c now
    builds a real throttle_packet_t (sync/seq/CRC8) with a slowly
    sweeping throttle field instead of a raw counter, .cproject gets the
    new src/common include path needed for throttle_protocol.h/crc8.h,
    and README.md records the confirmed end-to-end milestone.
    [main.c]
2026-08-08 Add wireless kill/start test, fix TX rate fighting the watchdog
    START_REQ now auto-tests every ~6s (idle throttle + flag held ~0.9s,
    well under MAX_CRANK_MS, always ends via voluntary release - blue LED
    while held, green on release). KILL is deliberately NOT automatic since
    it's sticky on the receiver; tx_send_kill is a debugger-settable one-shot
    instead, to avoid locking board B mid-test.
    Also fixes erratic servo motion observed during the plain throttle
    sweep: this bring-up TX was sending every 300ms, comfortably slower
    than WATCHDOG_RAMP_START_MS (175ms, tuned for the real protocol's 80Hz/
    12.5ms rate) - so the watchdog was very likely starting a ramp-to-idle
    in every single gap between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
    [main.c]
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2026-08-09 Drop handle-side battery monitoring entirely
    The handle will use standalone battery meters wired directly to the
    packs instead of an onboard sense circuit, so the ADC pin and the
    placeholder bar/buzzer scaffolding in handle_firmware.c (HANDLE_BATT,
    read_battery_mv, battery_tick, etc.) have no real hardware behind
    them and are just dead weight. Removes all of it; battery_monitor.h's
    shared math is now receiver-only (it already folds low-battery into
    the tri-color status LED's blink rate there rather than a bar/buzzer).
    Frees another ADC pin from the handle's pin budget on top of the
    AUX2 removal.
    [handle_firmware.c]
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2026-08-09 Expose cruise state on the receiver for a future indicator LED
    The receiver has always been oblivious to CMD_FLAG_CRUISE - the handle
    resolves cruise entirely on its own side (freezing the throttle it
    sends), so the receiver just applies whatever throttle value arrives.
    Adds g_cruise_active, purely for a real board's future cruise
    indicator LED to read - no control-flow decision depends on it.
    Lives in apply_aux_outputs() alongside g_aux1_state/g_aux2_state
    (same "record latest flag, no safety meaning" pattern), not inside
    handle_valid_packet() - a safety-reviewer pass on the first draft
    correctly flagged that placing it inside the kill/start/throttle
    sequence, even inertly, was the wrong p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
    [receiver_firmware.c]
2026-08-09 Overhaul receiver-prod status LED: bi-color + separate cruise LED
    Replaces the tri-color LED's blue-for-cranking + always-on heartbeat
    with a proper priority state machine (kill long-long > cranking
    yellow > running-proxy green > lub-dub heartbeat default), using the
    new shared src/common/led_blink.h sequencer so timing matches the
    handle exactly. The old prod_heartbeat_tick() and the green/blue
    writes inside prod_actuation_tick() are replaced by
    prod_status_led_tick() (running-proxy latch unchanged in logic, just
    moved to a tracked bool instead of inline GPIO writes so the
    heartbeat can check it) plus a separate prod_cruise_led_tick()
    reading the new g_cruise_active.
    PA11 needs relabeling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
    [prod_app.c]
2026-08-09 Overhaul handle-prod status LED: bi-color + separate cruise LED
    Mirrors the receiver-prod LED overhaul exactly, using the same
    src/common/led_blink.h patterns so both boards' red channel means
    the same thing with identical timing. New: a local-only running-proxy
    latch (g_handle_running_proxy, edge-tracked off g_start_hold_confirmed
    since there's no telemetry to confirm the real thing) that gates the
    heartbeat - this fixes the reported bug where the handle showed green
    immediately at boot, before ever starting.
    Cruise moves from the status LED's blue channel to a separate,
    dedicated LED (g_cruise_engaged, logic unchanged, just relocated).
    PA10 needs relabeling from LED_BLUE to CRUISE_LED in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
    [handle_app.c]
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2026-08-10 CubeMX regenerate: relabel LED_BLUE to CRUISE_LED on both boards
    Matches the pin rename already assumed by prod_app.c/handle_app.c
    (PA11 on receiver-prod, PA10 on handle-prod) - same pins, no
    reassignment, just the label so the code's CRUISE_LED_Pin/
    CRUISE_LED_GPIO_Port references resolve. Confirmed both boards build
    and the full LED overhaul (heartbeat, kill blink, cranking/running
    proxy, separate cruise LED) works on real hardware after physically
    disconnecting each tri-color LED's blue lead and wiring the new
    standalone cruise LEDs. Driver/CMSIS file changes in this commit are
    pure line-ending noise from the regenerate, no content difference.
    [handle-prod.ioc, main.h, receiver-prod.ioc]
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2026-08-14 Wire per-unit nRF24 addressing into the radio driver and both apps
    Implements the mechanism from ADR 0009: nrf24_handle_t gains an addr
    field (same parameterized-not-hardcoded pattern as hspi/ce_port/etc.),
    so nrf24.c stays fully unit-agnostic - it no longer hardcodes
    PLACEHOLDER_ADDR, only the still-open RF channel stays a placeholder.
    New src/common/unit_config.h (tracked in git, UNIT_NUMBER defaults to
    0xFF) is the single source of truth for a unit's identity. Both
    handle_app.c and prod_app.c build their 5-byte address from
    UNIT_NRF24_ADDR_PREFIX + UNIT_NUMBER and set it before calling
    nrf24_init(). UNIT_NUMBER == 0x00 is a hard compile-time #error, not
    a warning - a forgotten edit can't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
    [handle_app.c, nrf24.c, prod_app.c]
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

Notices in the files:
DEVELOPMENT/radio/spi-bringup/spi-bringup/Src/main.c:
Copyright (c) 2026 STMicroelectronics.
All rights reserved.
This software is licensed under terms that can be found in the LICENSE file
